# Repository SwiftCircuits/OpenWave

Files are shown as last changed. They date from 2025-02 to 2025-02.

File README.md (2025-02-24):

# OpenWave: Precision Arbitrary Waveform Generator

<div align="center">



[]()

**A dual-channel, high-precision waveform generator designed for control system analysis and system identification**

[Features](#features) • [Getting Started](#getting-started) • [Documentation](#documentation) • [Contributing](#contributing)

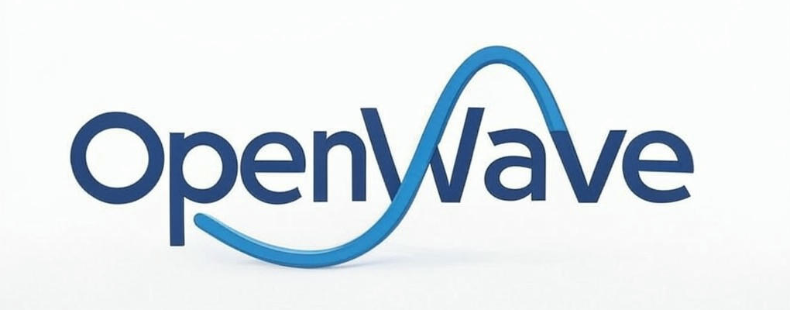
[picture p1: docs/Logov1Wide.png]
OpenWave Project Banner


</div>

## Why OpenWave?

Traditional arbitrary waveform generators often force a choice between expensive lab equipment or limited-capability hobby projects. OpenWave bridges this gap by providing professional-grade precision in an open-source design that prioritizes signal quality over raw speed. By focusing on the critical frequency range used in control systems and system identification (up to 500 kHz), we've optimized for exceptional signal quality and reliability.

### Key Features

- Dual independent channels with 16-bit resolution
- Optimized 500 kHz bandwidth with 80 dB SNR
- Sophisticated triggering system for precise control
- Multiple interface options: USB, Ethernet, and CAN
- Intuitive front panel control with LCD display
- Expansion capability through daughter board interface
- Precision temperature-monitored reference system
- Professional-grade signal filtering and conditioning

### Perfect For

- Control system development and testing
- System identification experiments
- Precision measurement applications
- Educational laboratory setups
- Research and development projects
- Industrial control system integration
- Signal processing development

## Technical Overview

OpenWave combines meticulous hardware design with flexible software to achieve exceptional signal quality:

### Signal Generation
- Dual 16-bit DACs (LTC2642-16) operating at 50 MSPS
- Third-order Sallen-Key filtering with Butterworth response
- Additional output stage conditioning
- Ultra-low noise power supply design
- Temperature-compensated reference system
- Comprehensive signal isolation and protection

### Control and Interface
- High-speed USB 2.0 interface
- 10/100 Ethernet connectivity
- Industrial-grade CAN interface
- Advanced trigger system with multiple modes:
  - Start trigger with precise timing
  - Level-sensitive pause control
  - Configurable burst mode
  - Status and peak detection outputs
- Intuitive front panel interface with LCD display

### Power System
- 12V DC input with protection
- Sophisticated multi-stage power architecture:
  - High-efficiency 5.5V pre-regulation
  - Ultra-low noise 5V analog supply
  - Clean 3.3V digital rail
  - Precision 3.3V reference
- Extensive power filtering and isolation

## Getting Started

### Current Status
This project is under active development. Current focus areas:
- Finalizing PCB layout and power distribution
- Implementing core firmware features
- Developing user interface systems
- Creating comprehensive documentation
- Establishing test procedures

### For Contributors

We welcome contributions in several areas:

**Hardware Development**
- PCB layout optimization
- Signal integrity improvements
- Power distribution refinement
- Manufacturing optimization
- Test coverage enhancement

**Firmware Development**
- STM32 core implementation
- Front panel interface development
- Communication protocol implementation
- Signal generation algorithms
- User interface refinement

**Documentation and Testing**
- System specification documentation
- Assembly and calibration procedures
- Performance verification methods
- Application examples
- User manual development

## Building OpenWave

### Hardware Requirements
- 4-layer PCB manufacturing capability
- SMD assembly equipment
- Precision test equipment:
  - Oscilloscope (>100MHz bandwidth)
  - Precision multimeter
  - Signal analyzer (recommended)
- STM32 programming capability
- Basic electronic assembly tools

### Software Requirements
- STM32CubeIDE development environment
- ARM GCC toolchain
- KiCad 7.0 or later
- Git version control
- Build system requirements (detailed in documentation)

## Documentation

> 🚧 Documentation is currently under development

Comprehensive documentation will cover:
- Complete system architecture
- Detailed theory of operation
- Assembly and testing procedures
- Calibration methodology
- Performance optimization
- Application examples
- Development guidelines

## Contributing

Your expertise can help make OpenWave better! Here's how you can contribute:

1. **Join Discussions**
   - Share your application requirements
   - Suggest performance improvements
   - Help define future features
   - Participate in design reviews

2. **Technical Contributions**
   - PCB design optimization
   - Firmware development
   - Documentation creation
   - Test procedure development
   - Performance validation

3. **Testing and Validation**
   - Prototype building and testing
   - Performance verification
   - Use case validation
   - Issue reporting and tracking

## Project Structure

```
/hardware           - KiCad design files
  /main            - Main board design
  /front_panel     - Front panel PCB
  /daughter_boards - Expansion board designs
  /manufacturing   - Production files
/firmware          - Source code
  /core            - Core STM32H7 functionality
  /front_panel     - STM32G0 interface code
  /libraries       - Shared libraries
  /tests           - Test suites
/docs              - Documentation
  /hardware        - Hardware documentation
  /firmware        - Software documentation
  /user            - User guides
  /testing         - Test procedures
```

## License

- Hardware: [CERN Open Hardware License Version 2](LICENSE-HARDWARE)
- Software: [MIT License](LICENSE-SOFTWARE)

## Acknowledgments

OpenWave builds on the work of many open-source projects and individuals. Special thanks to:
- The open hardware community for inspiration and shared knowledge
- Contributors who have helped shape the project's direction

## Contact and Support

- Create an issue for bugs or feature requests
- Join our discussions for general questions
- Email for other inquiries: constantinescu.alex02@gmail.com

---

<div align="center">

**[Back to Top](#openwave-precision-arbitrary-waveform-generator)**

</div>

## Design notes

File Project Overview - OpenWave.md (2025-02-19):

# Project Name

## Current Status
- Phase: Development
- Version: 0.1
- Last Updated: {{date}}

## Specifications
### Performance Targets
- Target 1: Value
- Target 2: Value

### Requirements
- Requirement 1
- Requirement 2

## Components Tracking

### Signal Chain
#### DAC
- Selected: Part Number
- Status: Ordered/Testing/Verified
- Performance:
    - Metric 1: Value
    - Metric 2: Value
- Issues:
    - [ ] Issue 1
    - [x] ~~Issue 2~~
        - Resolution

#### Output Stage
- Selected: Part Number
- Status: Evaluation
- Notes:
    - Observation 1
    - Observation 2

### Power System
- Architecture: Description
- Components:
    1. Component 1
        - Status
        - Performance
    2. Component 2
        - Status
        - Performance

## Development Progress

### Hardware
#### Schematic
- Status: In Progress
- Version: 0.1
- Outstanding Issues:
    - [ ] Issue 1
    - [ ] Issue 2
- Next Steps:
    - [ ] Step 1
    - [ ] Step 2

#### PCB
- Status: Planning
- Version: -
- Design Rules:
    - Rule 1
    - Rule 2
- Layout Considerations:
    - Consideration 1
    - Consideration 2

### Firmware
#### STM32CubeIDE Project
- Status: Initial Setup
- Configuration:
    - Setting 1
    - Setting 2
- Features:
    - [ ] Feature 1
    - [ ] Feature 2

#### USB Protocol
- Status: Planning
- Requirements:
    - Requirement 1
    - Requirement 2

## Testing
### Test Procedures
1. Procedure 1
    - Steps
    - Expected Results
2. Procedure 2
    - Steps
    - Expected Results

### Results
#### Test Run {{date}}
- Test 1: Pass/Fail
    - Notes
- Test 2: Pass/Fail
    - Notes

## Documentation
### User Manual
- Status: Not Started
- Sections:
    - [ ] Section 1
    - [ ] Section 2

### Technical Documentation
- Status: In Progress
- Sections:
    - [ ] Section 1
    - [ ] Section 2

## References
- Reference 1
- Reference 2

## Change Log
### Version 0.1 ({{date}})
- Initial setup
- Key decisions made

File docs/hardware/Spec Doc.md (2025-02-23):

# Arbitrary Waveform Generator

## System Overview

The arbitrary waveform generator represents a precision-focused instrument designed specifically for system identification and control system analysis applications. Operating at frequencies up to 500 kHz with 80 dB SNR, it delivers exceptional waveform generation through a dual-channel output system. The design philosophy emphasizes signal quality and measurement precision over raw speed, making it particularly suitable for control systems applications where signal integrity is paramount.

## Signal Chain Architecture

The signal generation path implements a carefully optimized serial interface approach, prioritizing signal integrity and reliability over raw throughput. The architecture centers around high-precision 16-bit DACs (LTC2642-16) with meticulous attention to power supply design and filtering to achieve superior signal quality.

Key architectural decisions include:
- Serial interface communication at 50 MHz
- Dual independent signal channels
- Hardware-level trigger processing
- Dedicated front panel processor for user interface
- Multi-stage filtering approach
- Temperature-compensated reference system

Our design philosophy acknowledges that most real-world control systems operate well below 500 kHz, allowing us to optimize for measurement accuracy and signal purity. Each component in the signal chain has been selected based on empirical evaluation and simulation results.

## Power System Architecture

The power system implements a sophisticated cascaded multi-rail design optimized for ultra-low-noise operation through a 12V input. Special attention has been paid to power supply rejection and filtering at each stage.

### Input Power
Requirements:
- 12V DC input via barrel connector (5.5mm × 2.1mm)
- Input voltage range: 11V to 13V
- Power budget: 5-7W total system draw
- Reverse polarity protection through series MOSFET
- Inrush current limiting
- Purpose: Primary system power input

### Power Rails
The system implements a carefully orchestrated cascade of power supplies:

- 5.5V Main Rail (Switching Supply):
  - Input: 12V DC
  - Output: 5.5V
  - Implementation: TPSM863252 switching regulator
  - High efficiency (>85%)
  - Switching frequency >1MHz
  - Custom RLC filter network:
    - 22µH inductor for switching noise suppression
    - Optimized capacitor values for minimal resonance
    - Damping resistors for transient response
  - Purpose: Pre-regulation for other voltage rails

- 5V Analog Rail (Low-Noise LDO):
  - Input: 5.5V from switching supply
  - Output: 5V
  - Implementation: Ultra-low noise linear regulator
  - PSRR > 80 dB at 100 kHz
  - Output noise < 10µV RMS (10Hz to 100kHz)
  - Purpose: DAC and op-amp power supply

- 3.3V Digital Rail (LDO):
  - Input: 5.5V from switching supply
  - Output: 3.3V at 500mA
  - Moderate PSRR requirements (>60 dB)
  - Fast transient response
  - Purpose: Digital logic power supply

- 3.3V Reference Voltage (Precision LDO):
  - Implementation: REF3333 precision reference
  - Initial accuracy < 0.1%
  - Temperature coefficient < 25ppm/°C
  - Ultra-low noise characteristics
  - Purpose: DAC reference voltage
  - Temperature monitored for potential compensation

### Power Distribution
The power distribution system employs:
- Separate analog and digital power planes
- Star-point grounding topology
- Independent filtering for each major subsystem
- Balanced power and return paths
- Local decoupling at each IC
- Bulk decoupling at power entry points

## Control and Communication

### Multiple Interface Options
The system implements several communication interfaces:

- USB Interface:
  - High-speed USB 2.0 implementation
  - Command protocol support
  - Streaming data capability
  - Built-in device firmware upgrade capability
  - ESD protection and filtering
  - Purpose: Primary computer interface

- Ethernet Interface:
  - Implementation: W5500 hardwired TCP/IP controller
  - 10/100 Mbps support
  - Independent 25MHz crystal
  - Magnetic isolation
  - TCP/IP protocol support
  - Purpose: Network connectivity and remote control

- CAN Interface:
  - Standard CAN 2.0B support
  - Galvanic isolation
  - Configurable bit rate up to 1Mbps
  - Termination options
  - Purpose: System synchronization and industrial control integration

### Trigger System
The trigger system provides comprehensive synchronization capabilities:

Input Triggers (3.3V logic):
- Start trigger: Initiates waveform generation
  - Rising edge sensitive
  - Configurable debounce
  - Protected input structure
- Pause trigger: Suspends output while active
  - Level-sensitive operation
  - Synchronous output suspension
  - Glitch filtering
- Burst trigger: Generates predetermined sample count
  - Software-configurable burst length
  - Precise timing control
  - Automatic termination

Output Triggers (3.3V logic):
- Started signal: Indicates active generation
  - Direct status indication
  - Low-latency response
- Peak detection: Signals waveform peaks
  - Software-configured threshold
  - Minimal delay implementation
- VRef output: Buffered reference voltage
  - Unity-gain buffered output
  - Low impedance drive
  - Filtered output stage

All triggers feature:
- EMI filtering
- ESD protection
- Schmitt trigger inputs where applicable
- Output short circuit protection

### Temperature Monitoring
The system implements dual temperature monitoring:
- Reference section sensor
  - Located near voltage reference
  - 0.5°C accuracy
  - Continuous monitoring
- Microcontroller section sensor
  - System temperature monitoring
  - Thermal protection implementation
- Look-up table based compensation
  - Temperature-dependent calibration
  - Digital compensation
- Purpose: System calibration and thermal monitoring

## Analog Signal Path

### DAC Implementation
The system utilizes dual LTC2642-16 DACs:
- 16-bit resolution
- 50 MSPS update rate
- Voltage output configuration
- Serial interface at 50 MHz
- Reference buffering
- Power supply filtering

### Output Filtering
Multi-stage filtering approach:

First Stage - Third Order Sallen-Key:
- Butterworth response characteristics
- 850 kHz cutoff frequency
- Minimal pass-band ripple
- Optimized component values
- Simulated phase response

Second Stage - Unity Gain Buffer:
- Low-noise operational amplifier
- Additional RC filtering network
- Output protection
- 50Ω drive capability

### Performance Optimization
- Careful PCB layout for analog section
- Localized power filtering
- Shield traces where necessary
- Minimize trace lengths
- Matched delay paths

## User Interface

### Front Panel Implementation
The front panel provides comprehensive user control through:

Physical Interface:
- Three precision potentiometers
  - Parameter adjustment
  - High-quality, panel-mount design
  - Metal shaft construction
- Three tactile control buttons
  - Mode selection
  - Menu navigation
  - System control
- LCD display
  - Parameter visualization
  - System status display
  - Menu system
- Five mode indication LEDs
- Status LED indicators

### Display Interface
The LCD implements:
- Current operating mode display
- Parameter value indication
- System status information
- Optional waveform preview
- Temperature and calibration status
- Menu system for configuration

## System Architecture

### Main Board
Core Components:
- STM32H743VIT6 microcontroller
  - 480 MHz operation
  - 1MB RAM
  - Extensive peripheral set
- 16 MB Flash memory
- Dual 16-bit DACs (LTC2642-16)
- Third-order Sallen-Key filters
- Unity gain output amplifiers
- Dual temperature sensors
- Level shifters for DAC communication
- Debug interfaces and indicators

### Front Panel Board
Interface Components:
- STM32G0B1 microcontroller
  - User interface handling
  - LED control
  - Parameter reading
- Interface elements
- Status indicators
- FPC connection to main board

### Expansion Capabilities
The system includes provisions for:
- Daughter board interface
  - Power distribution
  - Communication buses
  - Control signals
- Additional filtering options
- Enhanced trigger capabilities
- Wireless connectivity options

## PCB Implementation

### Board Architecture
- 4-layer implementation
- Layer stack-up:
  - Top: Signal
  - Layer 2: Ground plane
  - Layer 3: Power planes
  - Bottom: Signal and power
- Controlled impedance throughout
- Single ground plane philosophy
- Careful return path consideration

### Critical Areas
- Analog section isolation
- Power supply placement
- Ground plane integrity
- High-speed signal routing
- Thermal considerations

### Manufacturing Considerations
- Standard FR4 material
- 1oz copper weight
- Controlled impedance requirements
- Through-hole and SMD mixed technology
- Assembly considerations
- Test point access

## Performance Specifications

### Signal Generation
- Maximum frequency: 500 kHz
- Resolution: 16-bit
- SNR: > 80 dB
- THD: < -75 dB
- Output filtering: Third-order Butterworth
- Channel-to-channel skew: < 10ns

### System Operation
- Trigger latency: < 100ns
- Temperature stability: < 50ppm/°C
- Start-up time: < 100ms
- USB/Ethernet latency: < 1ms typical

## Future Considerations

The design includes provisions for:
- Additional interface options
- Enhanced trigger capabilities
- Wireless connectivity through daughter boards
- Advanced filtering implementations
- Remote control capabilities
- Battery operation options

Note: All specifications subject to verification during detailed design phase.

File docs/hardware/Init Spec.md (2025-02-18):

# Arbitrary Waveform Generator: System Architecture and Requirements

## System Overview

The arbitrary waveform generator is designed as a USB-powered, battery-backed device for system identification and control system analysis. Operating at frequencies up to 8 MHz with 60 dB SNR, it provides precise waveform generation through a dual-channel output system.

## Signal Chain Architecture

The signal generation path is designed around a serial interface approach, prioritizing reliability and simplicity over raw speed. This architectural choice shapes our entire signal chain, from memory management to analog output stage.

Our design philosophy emphasizes practical performance targets that align with real-world control system needs. For system identification work, timing consistency and signal quality are more critical than extremely high frequencies. Each component in our signal chain is selected with this philosophy in mind:

### Digital Signal Generation
Primary MCU requirements:
- DMA capabilities for continuous data streaming
- Hardware floating-point for mathematical operations
- Multiple high-resolution timer units
- Sufficient GPIO for parallel DAC interface
- USB peripheral with high-speed capability
- CAN peripheral for auxiliary communication

### Memory System

### Memory Strategy and Buffer Management

Our memory architecture is built around the capabilities of modern microcontrollers, taking advantage of their substantial internal RAM and efficient DMA controllers. This approach eliminates the complexity and potential signal integrity issues of external RAM while providing more than adequate performance for our needs.

Memory Requirements Analysis:
At our target 100 MSPS with 12-bit samples, our theoretical bandwidth is 1.2 Gbps per channel. However, our SPI interface serializes this data at up to 100 MHz, making the actual memory throughput requirements much more manageable. For a typical 1ms control system time step, we need only 150 KB per channel including double buffering, well within the capabilities of modern MCU internal RAM.

RAM Organization:
- Primary waveform buffer in internal MCU RAM, eliminating external memory complexity
- Double-buffering scheme for seamless output, with each buffer sized for complete control system time steps
- Buffer sizing follows: (sample_rate × bits_per_sample × channels × buffer_time)
- Typical buffer depth: 4-16K samples per channel, optimized for common control system update rates

DMA Configuration:
- Circular buffer mode for continuous output
- Interrupt on half-buffer completion
- Buffer swap without output glitches
- Error detection and recovery mechanisms

Purpose: 
- Ensuring continuous waveform generation
- Supporting real-time parameter updates
- Maintaining timing accuracy
- Enabling smooth transitions between waveforms
- Concurrent access capability for DMA and CPU
- Purpose: Active waveform buffers and computation workspace

Flash Storage Requirements:
- QSPI interface for high-speed access
- Minimum 32 Mbit capacity
- Purpose: 
  - Storage for custom waveform patterns
  - Configuration settings
  - Calibration data
  - Lookup tables for standard waveforms

### Digital-to-Analog Conversion

DAC Requirements:
- 50-100 MSPS update rate with SPI/I²S interface
- 10-bit resolution
- Parallel interface to minimize latency
- Current-output architecture
- SNR > 60 dB
- THD < -60 dB
- Settling time < 3ns
- Purpose: Converting digital patterns to analog signals

### Analog Output Stage

Amplification Requirements:
- Bandwidth > 100 MHz
- Slew rate > 1000 V/µs
- Output current > 50mA for 50Ω loads
- Input bias current < 1µA
- Low input-referred noise (< 5 nV/√Hz)
- Power supply rejection > 60 dB
- Purpose: Signal conditioning and impedance matching

### Clocking System

Initial Implementation:
- External crystal oscillator as reference
- Internal PLL for frequency generation
- Clock distribution with controlled impedance
- Purpose: System timing and DAC clock generation

Future Upgrade Path:
- Space for dedicated clock generator
- Power supply provisions
- Clock distribution routing channels
- Test points for performance verification

## Power System Architecture

The power system implements a multi-rail design with separate charging and operational paths:

### Input and Charging
Requirements:
- USB power negotiation (5V, up to 3A)
- Separate charging and operational paths
- Battery protection features
- Charge status monitoring
- Purpose: Power input and battery management

### Power Rails
Multiple independent supplies:
- 3.3V Digital Rail:
  - Low noise for digital circuits
  - High current capability
  - Fast transient response
  - Purpose: Digital logic power

- 3.3V Analog Rail:
  - Ultra-low noise (< 10µV RMS)
  - High PSRR (> 80 dB)
  - Purpose: Sensitive analog circuits

- 5V Analog Rail:
  - Low noise characteristics
  - High current capability
  - Purpose: Op-amp power supply

- Reference Voltage:
  - Ultra-stable output
  - Temperature compensated
  - Purpose: DAC reference

### Battery Management
Requirements:
- Lithium battery support
- Smart charging control
- Voltage and current monitoring
- Temperature monitoring
- Purpose: Portable operation support

## Control and Communication

### USB Interface
Requirements:
- High-speed USB 2.0 capability
- Robust USB power delivery
- Command protocol support
- Streaming data capability
- Purpose: Primary computer interface

### CAN Interface
Requirements:
- Standard CAN 2.0B support
- Isolated interface
- Configurable bit rate
- Purpose: System synchronization and auxiliary control

### Temperature Monitoring
System includes:
- Two temperature sensors
- Compensation algorithms
- Purpose: System calibration and thermal monitoring

## PCB Design Requirements

### Signal Integrity
- Controlled impedance for critical traces
- Proper stackup for high-speed signals
- Ground plane strategy
- Power plane partitioning
- Purpose: Maintaining signal quality

### Layout Considerations
- Separate analog and digital sections
- Critical component placement
- Thermal management
- EMI mitigation
- Future upgrade provisions
- Purpose: System performance optimization

## Calibration System

### Temperature Compensation
- Regular sensor sampling
- Gradient monitoring
- Compensation tables
- Purpose: Maintaining accuracy across temperature

### Signal Calibration
- Gain calibration
- Offset adjustment
- Frequency response characterization
- Purpose: Output accuracy verification

## Outputs and Interfaces

### Signal Outputs
- Two independent channels
- 50Ω output impedance
- Voltage range: 0 to 3.3V
- BNC or SMA connectors
- Purpose: Waveform output

### Trigger System
Implementation Strategy:
- Utilize MCU internal comparators for trigger detection
- Internal reference voltage for threshold setting
- Software-configurable hysteresis
- Timer-based output generation

Input Characteristics:
- Voltage range: 0-3.3V
- Software-adjustable threshold
- Configurable hysteresis through MCU comparator
- Input protection with current limiting and TVS
- Minimum pulse width: 100ns

Output Characteristics:
- 3.3V CMOS level output
- Timer-controlled for precise timing
- Programmable delay (100ns resolution)
- Short circuit and ESD protected
- Drive capability: up to 8mA

This approach simplifies hardware while maintaining functionality through careful use of MCU peripherals.
- Purpose: System synchronization

## Performance Targets

### Signal Generation
- Maximum frequency: 8 MHz
- SNR: > 60 dB
- THD: < -60 dB
- Channel-to-channel skew: < 10ns

### System Operation
- Initial lock time: < 100ms
- Trigger latency: < 100ns
- Temperature stability: < 50ppm/°C
- Battery operation: > 2 hours continuous

## Future Expansion Considerations

The design includes provisions for:
- Dedicated clock generator upgrade
- Additional memory expansion
- Enhanced trigger capabilities
- Ethernet interface addition
- Purpose: Future feature enhancement

Note: This specification focuses on system properties and requirements rather than specific component selections. Implementation details will be determined during the detailed design phase.

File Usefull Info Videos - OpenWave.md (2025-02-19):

# Mixed-Signal Design Guidelines for AWG Project
*Extracted from [Phil's Lab video](https://www.youtube.com/watch?v=v6fTa6LRJLI&ab_channel=Phil%E2%80%99sLab), focusing on principles relevant to our arbitrary waveform generator design*

## 1. Ground Plane Management (0:00-4:39)
For our AWG design, the key takeaways are:
- Use a unified ground plane unless there's a compelling reason not to
- In our 4-layer design, we should maintain solid ground planes on inner layers
- Keep signal traces away from voids in the ground plane
- Maintain minimum spacing between signal and ground layers
  - Recommended: 0.11mm between layers for optimal coupling
- This directly applies to our STM32H743 + LTC2642 DAC design

## 2. Digital-Analog Separation (4:39-9:24)
Critical for our AWG implementation:
- Place digital section (STM32H743, flash memory) distinctly separate from analog section (DAC, op-amps)
- Use the DAC's pinout to define the boundary:
  - Digital interface pins should face the digital section
  - Analog pins should face the analog section
- Consider 3D separation if board space is tight
- Implement via fencing between domains:
  - Space vias at maximum 1/10th of the wavelength of highest frequency of interest
  - For our 2-5MHz design, this gives us a good margin

## 3. Domain Crossing Strategy (9:24-11:55)
Applicable to our control signals:
- Use Pi filters when crossing from digital to analog domains
- Filter composition:
  - Capacitor on digital side
  - Series element (resistor or ferrite bead)
  - Capacitor on analog side
- Particularly important for our MCU control signals to the analog section
- Consider edge rate reduction for digital signals entering analog domain

## 4. Power Supply Separation (11:55-15:09)
Directly relevant to our power architecture:
- Maintain separate supplies for digital and analog sections
- Our implementation matches recommendations:
  - Digital: 3.3V with higher current capacity for STM32
  - Analog: Clean 3.3V reference for DAC
  - 5V rail for op-amps
- Use Pi filters for power supply noise reduction
- Place initial filter near input connector
- Consider additional filtering for analog supplies

## 5. Component Selection Guidelines (15:09-17:47)
Critical considerations for our design:
- Power regulators: Check noise specifications and PSRR
- For our DAC and op-amps:
  - Consider pin arrangement for optimal layout
  - Look for clear separation between digital and analog pins
  - Check noise specifications and settling time
- Consider package types that facilitate clear domain separation

## Implementation Notes for Our AWG
- Our proposed LTC2642 DAC aligns well with these guidelines, having clear digital/analog pin separation
- The LMH6658 op-amp choice supports our bandwidth requirements while maintaining good noise characteristics
- The power system design with TPSM863252 and separate LDOs follows these recommendations
- Consider adding more via fencing between domains in the next revision

# Thermal Design Guidelines for AWG Project
*Extracted from [Phil's Lab video](https://www.youtube.com/watch?v=8v-wC5cM_Yk&ab_channel=Phil%E2%80%99sLab), focusing on principles relevant to our arbitrary waveform generator design*

## Power Plane Dimensioning (1:17-4:30)
Our AWG design requires careful consideration of power distribution, particularly for the analog and digital domains. The key principles to apply are:

The IPC-2221 specification provides the foundation for calculating appropriate trace widths. For our design, we should consider:
- Different requirements for internal vs. external layers (internal layers need ~2.5x wider traces)
- Temperature rise calculations based on our expected operating environment
- Non-linear relationship between current capacity and trace width

For our specific power rails:
- 12V input: Requires wide traces due to higher current
- 5V rail (TPSM863252): Must handle 1.5A minimum
- 3.3V digital (for STM32): Needs ~500mA capacity
- 3.3V analog: Lower current (~200mA) but requires special attention to noise

## Linear Regulator Considerations (7:03-11:55)
This section is particularly relevant for our design's analog power supplies. Key points:

Power Dissipation Calculation:
```
P_dissipated = (V_in - V_out) × I_out
```

For our design:
- TPS70933DBVR (3.3V analog): Must consider noise and thermal characteristics
- AP7363-33D (3.3V digital): Higher current requires better thermal management
- REF3333 (precision reference): Requires stable temperature for accuracy

## Package Selection Guidelines (9:42-13:15)
Critical considerations for our power components:

Thermal Resistance:
- Junction-to-ambient thermal resistance (θJA) is crucial
- Larger packages generally offer better thermal performance
- Thermal pad presence significantly impacts heat dissipation

For our specific components:
- TPSM863252: Must handle the highest power dissipation
- Linear regulators: Need careful thermal design due to voltage drop
- Reference voltage IC: Requires temperature stability for accuracy

## Thermal Via Implementation (13:16-18:00)
Essential guidelines for our power components:

Via Design:
- Optimal via hole diameter: 0.25mm - 0.3mm
- Multiple parallel vias reduce thermal resistance
- Place vias directly under thermal pads
- Consider solder wicking during assembly

For our layout:
- Place thermal vias around regulator thermal pads
- Connect to internal ground planes for heat spreading
- Consider additional copper pours for better heat dissipation

## Application to Our AWG Design
Specific recommendations for our implementation:

1. Power System Layout:
   - Separate analog and digital power planes
   - Use thermal relief for through-hole components
   - Implement copper balancing for assembly reliability

2. Component Placement:
   - Keep heat-generating components (TPSM863252, linear regulators) separated
   - Consider airflow patterns in enclosure
   - Maintain thermal isolation between analog and digital sections

3. Thermal Management Strategy:
   - Use multiple ground planes for heat spreading
   - Implement proper thermal via arrays under power components
   - Consider ambient temperature range (0°C to 50°C per spec)

4. Critical Areas Requiring Attention:
   - Main switching regulator (TPSM863252)
   - Analog supply linear regulator
   - Precision voltage reference
   - Output amplifier stage

By following these guidelines, we can ensure reliable operation across our specified temperature range while maintaining the signal integrity required for precise waveform generation.

# RF Design Guidelines for AWG Project
*Extracted from [Phil's Lab video](https://www.youtube.com/watch?v=_Hfzq1QES-Q&t=2s&ab_channel=Phil%E2%80%99sLab), with focus on principles relevant to our arbitrary waveform generator design operating up to 5MHz*

## Critical Length Calculations (0:00-4:42)
While our AWG operates at lower frequencies than typical RF designs, understanding critical length is still important for signal integrity. The critical length determines when we need to consider transmission line effects:

For microstrip traces (outer layer):
```
Critical Length = (c / f) × (1 / √εeff) / 12

Where:
c = speed of light (3×10⁸ m/s)
f = frequency of interest
εeff = effective dielectric constant
```

For our maximum frequency of 5MHz:
- Critical length ≈ 2.5 meters
- While this suggests we don't need strict RF practices, following good RF design principles will improve signal quality

## PCB Stack-up Considerations (4:42-8:51)
For our 4-layer design:

Inner layers:
- Layer 2: Solid ground plane under analog sections
- Layer 3: Power distribution and additional ground

Outer layers:
- Top layer: Signal routing with controlled impedance where needed
- Bottom layer: Additional routing and ground planes

This arrangement provides excellent shielding and signal integrity for our analog sections.

## Controlled Impedance Traces (8:51-12:33)
For our analog output path:

Calculating trace width for 50Ω impedance:
- Consider PCB manufacturer's stack-up specifications
- For typical 4-layer board with FR4 (εr = 4.6):
  - Height to reference plane: 0.2mm
  - 1oz copper thickness: 35µm
  - Resulting trace width: approximately 0.3mm

## Managing Impedance Discontinuities (12:33-14:33)
Particularly important for our DAC output and op-amp sections:

- When transitioning from component pads to traces:
  - Use gradual transitions rather than abrupt changes
  - For our DAC outputs, implement smooth tapering from pads
  - Consider via transitions carefully near sensitive analog paths

## Clearance Guidelines (14:33-15:18)
Critical for maintaining signal integrity:

Component Placement Strategy:
- Keep DAC and analog output section well separated from digital circuits
- Maintain distance between high-speed digital signals and analog paths
- Consider magnetic field effects from power supply components
- Place sensitive analog components away from switching regulators

## Application to Our AWG Design
Specific recommendations for implementation:

Signal Path Design:
1. DAC Output Stage:
   - Implement controlled impedance traces for critical analog paths
   - Use gradual transitions from DAC output pads
   - Maintain consistent ground reference under signal paths

2. Analog Power Distribution:
   - Keep analog power planes well-isolated from digital sections
   - Use separate ground planes for analog and digital domains
   - Implement star grounding topology for analog sections

3. Component Placement:
   - Group analog components together
   - Maintain maximum practical separation between analog and digital sections
   - Consider airflow and thermal effects on precision components

4. Critical Areas Requiring Special Attention:
   - DAC output traces
   - Op-amp feedback networks
   - Reference voltage distribution
   - Analog power supply traces

## Implementation Notes
While our maximum frequency of 5MHz doesn't require strict RF practices, following these guidelines will improve performance:

1. Signal Path:
   - Use controlled impedance where practical
   - Maintain ground plane integrity
   - Keep analog traces short and direct

2. Shielding:
   - Use ground planes effectively
   - Consider local shielding for sensitive sections
   - Implement proper via fencing around analog sections

3. Grounding:
   - Use solid ground planes
   - Implement proper ground separation
   - Consider return current paths

By following these guidelines, we can ensure optimal signal integrity and minimize unwanted interference in our AWG design, even though we're operating at relatively lower frequencies than typical RF applications.

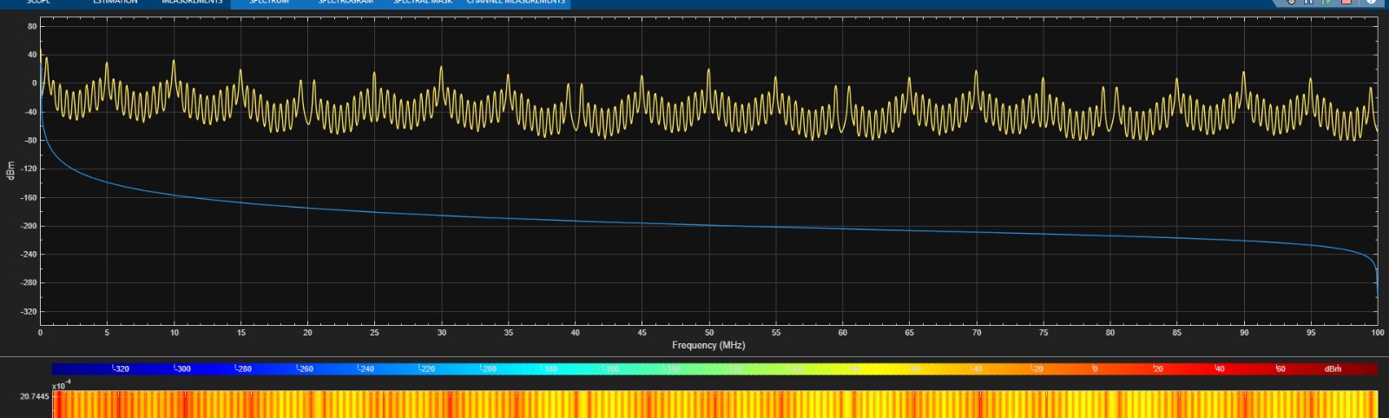
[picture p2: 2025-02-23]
docs/hardware/PowerFilterResponse.jpg

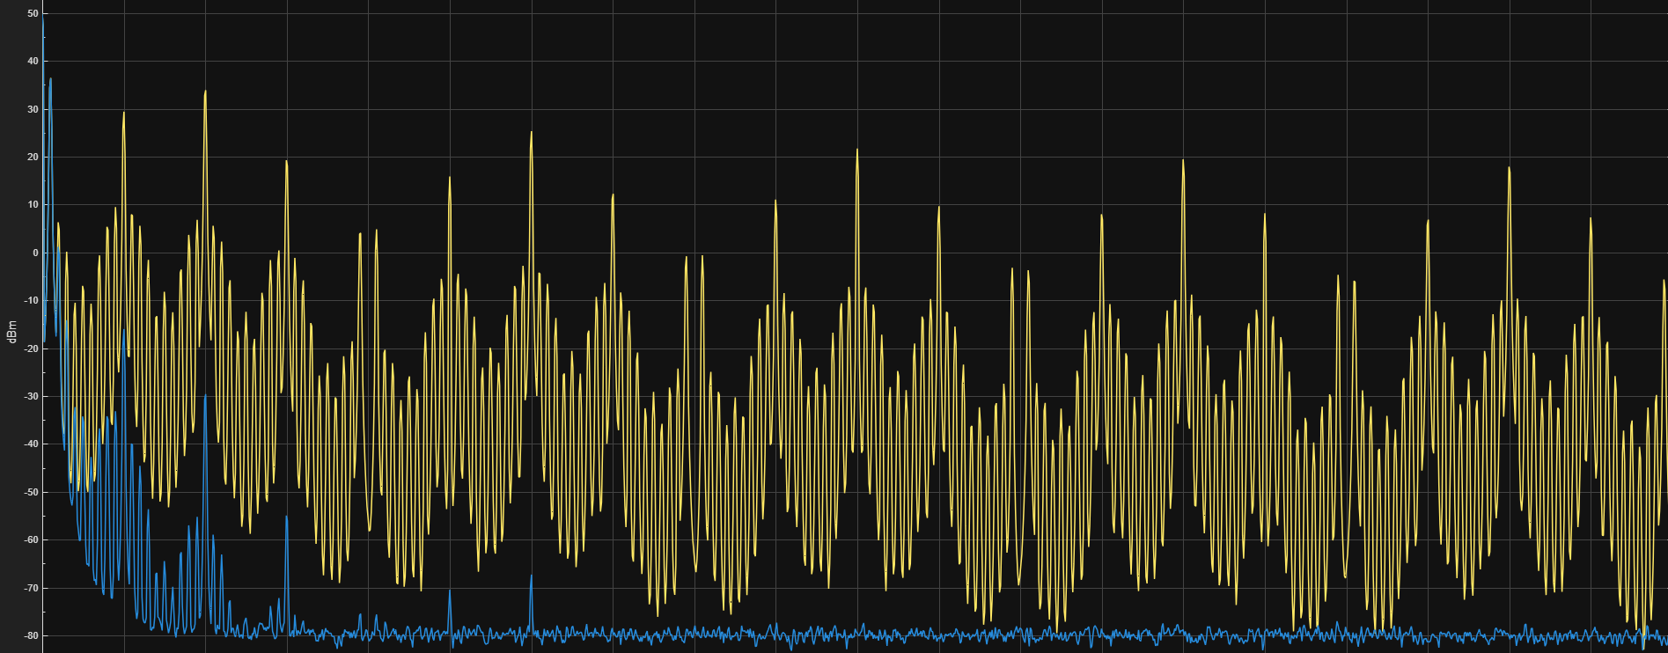
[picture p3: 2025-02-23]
docs/hardware/OutputFilterResponse.png

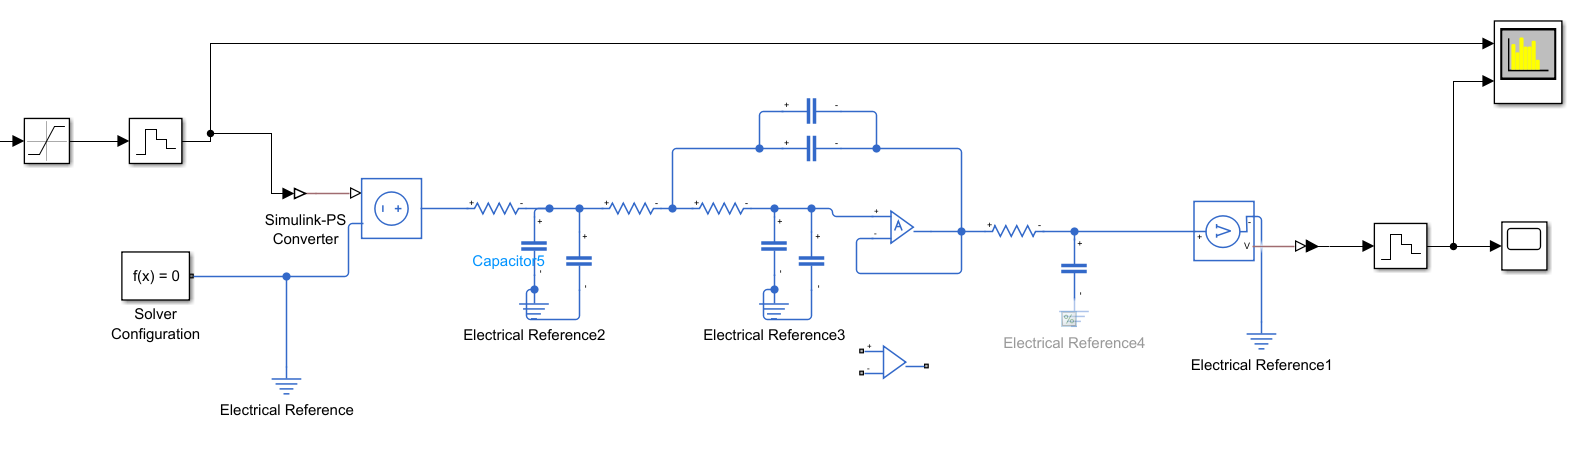
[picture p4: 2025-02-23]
docs/hardware/OutputFilterDesign.png

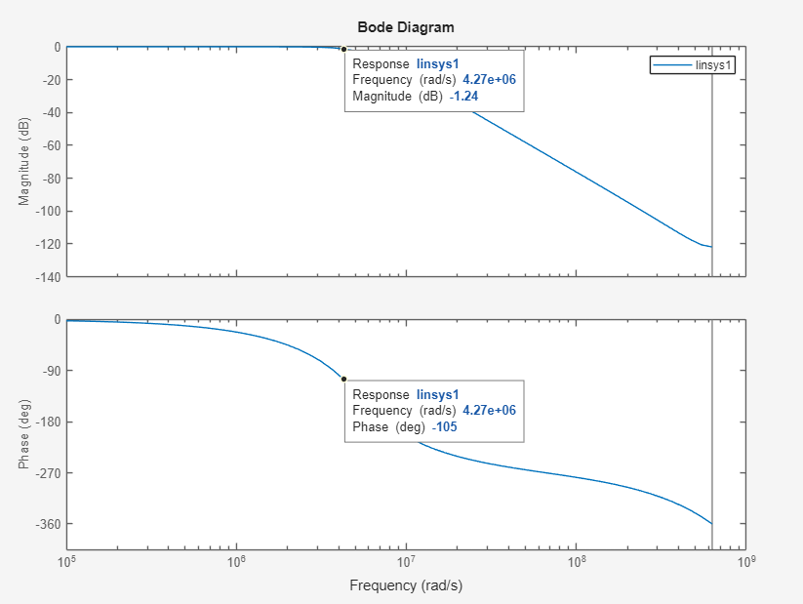
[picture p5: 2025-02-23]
docs/hardware/OutputFilterBode.png

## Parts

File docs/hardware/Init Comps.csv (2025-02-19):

Component Name | Component Type | Use | Option 1 | Link 1 | JLC # | Option 2 | Link 2 | Spec
DAC | Digital-to-Analog Converter | Signal Generation | LTC2642IMS-12#PBF | https://ro.mouser.com/ProductDetail/Analog-Devices/LTC2642IMS-12PBF?qs=hVkxg5c3xu%2FRHnABAf4DOg%3D%3D | C580595 | AD5512AACPZ | https://ro.mouser.com/ProductDetail/Analog-Devices/AD5512AACPZ-REEL7?qs=NmRFExCfTkH4RrvEIUo0Ug%3D%3D | 50-100 MSPS via SPI; 12-bit resolution; SNR > 60 dB; THD < -60 dB; Settling time < 5ns
Output Amplifier | Operational Amplifier | Signal Conditioning | LMH6658MAX/NOPB | https://ro.mouser.com/ProductDetail/Texas-Instruments/LMH6658MAX-NOPB?qs=7lkVKPoqpbYvQxLHeSqxGQ%3D%3D | N/A | LMH6624MF/NOPB | https://jlcpcb.com/partdetail/TexasInstruments-LMH6639MFNOPB/C131982 | Bandwidth > 100 MHz; Slew rate > 500 V/Âµs; Output current > 50mA for 50Î© loads; Low noise < 5 nV/âˆšHz
MCU | Microcontroller | System Control | STM32H743VIT6 | https://ro.mouser.com/ProductDetail/STMicroelectronics/STM32H743VIT6?qs=FNcb6ahWXRw0Me5k2ZHgWw%3D%3D | C114409 | N/A | N/A | ARM Cortex-M4/M7; â‰¥100MHz; 256KB Flash; 128KB RAM; USB; SPI; CAN; ADC 12-bit
Battery Management IC | Power Supply | Clean Analog Power | TPS70933DBVR | https://ro.mouser.com/ProductDetail/Texas-Instruments/TPS70933DBVR?qs=Z9twEOuL%252B%2FJOaGO60BtvLA%3D%3D | C89347 | TBD-REG2 | # | 3.3V output; Ultra-low noise (<10ÂµV RMS); High PSRR (>80 dB)
 | Power Supply | Digital Logic Power | AP7363-33D-13 | https://ro.mouser.com/ProductDetail/Diodes-Incorporated/AP7363-33D-13?qs=wo71MgyKIyHiOg1BWxA5bA%3D%3D | C108723 | TBD-REG4 | # | 3.3V output; High current capability; Fast transient response
Voltage Regulator (3v3 Analog) | Power Supply | Clean Analog Power | TPSM863252 | https://ro.mouser.com/ProductDetail/Texas-Instruments/TPSM863252RDXR?qs=17ckDYBRdem3VGqByrpWcQ%3D%3D | C19190416 | TBD-REG6 | # | 5V output; Fast transient response
Voltage Regulator (3v3 Digital) | Power Supply | Stable Ref Voltage | REF3333AIDBZR | https://ro.mouser.com/ProductDetail/Texas-Instruments/REF3333AIDBZR?qs=7KoJEllG3D1OY7cEjajdfg%3D%3D | C130016 | TBD-REF2 | # | 3.3V output; Very high stability (Zener?)
Voltage Regulator (5V Analog) | USB Controller | PC Communication | TBD-USB1 | # |  | TBD-USB2 | # | USB 2.0 Full Speed; 5V tolerance; ESD protection
Voltage Reference (3v3) | Communication Interface | CAN Bus Interface | TBD-CAN1 | # |  | TBD-CAN2 | # | CAN 2.0B compatible; 3.3V interface; ISO1050 compliant
USB Interface | Clock Source | System Timing | TBD-XTAL1 | # |  | TBD-XTAL2 | # | High stability; Low phase noise; Temperature compensated
CAN Transceiver | User Input | Parameter Control | TBD-POT1 | # |  | TBD-POT2 | # | 10-100kÎ©; 1% linearity; Metal shaft; >10k cycle life
Crystal Oscillator | Status Indicator | User Feedback | TBD-LED1 | # |  | TBD-LED2 | # | 3mm or 5mm; 5mA operation; Various colors; 120Â° viewing angle
Potentiometer | User Input | Control Selection | TBD-SW1 | # |  | TBD-SW2 | # | Tactile feedback; 100k cycle life; 150-250gf operating force
LED | Protection | I/O Protection | TBD-TVS1 | # |  | TBD-TVS2 | # | Low capacitance; Fast response; Appropriate voltage rating
Tactile Switch | Connector | Power & Data Input | TBD-USBC1 | # |  | TBD-USBC2 | # | USB 2.0 compatible; Through-hole mounting; 5A current rating; Shielded
TVS Diode | Connector | Signal Output | TBD-BNC1 | # |  | TBD-BNC2 | # | 50Î© impedance; Panel mount; Gold plated; DC-1GHz bandwidth
USB-C Connector | Connector | Battery Connection | TBD-BATCON1 | # |  | TBD-BATCON2 | # | JST-PH or similar; 2A rating; Polarized; Locking
BNC Connector | Connector | Programming/Debug | TBD-DBG1 | # |  | TBD-DBG2 | # | SWD compatible; 2x5 1.27mm pitch; Keyed
Battery Connector | Connector | CAN Bus | TBD-CANCON1 | # |  | TBD-CANCON2 | # | 4-pin locking; Polarized; 2A rating
Debug Connector | Storage | Waveform Storage | TBD-FLASH1 | # |  | TBD-FLASH2 | # | 32Mbit minimum; SPI interface; >10MHz clock
CAN Connector | Protection | Battery Safety | TBD-BPROT1 | # |  | TBD-BPROT2 | # | Overcurrent; Overvoltage; Temperature protection
Flash Memory | EMI Suppression | Power Filtering | TBD-FB1 | # |  | TBD-FB2 | # | 600Î© @ 100MHz; 1.5A rating
Battery Protection | Passive | Power Decoupling | TBD-CAP1 | # |  | TBD-CAP2 | # | 0.1ÂµF & 10ÂµF X5R/X7R; Low ESR
Ferrite Bead | Passive | Power Filtering | TBD-IND1 | # |  | TBD-IND2 | # | 10ÂµH; Low DCR; >1A rating
Bypass Capacitors | Passive | Current Monitoring | TBD-RSENSE1 | # |  | TBD-RSENSE2 | # | 0.05Î©; 1%; 0.5W
Power Inductors | Sensor | Thermal Monitoring | TBD-TEMP1 | # |  | TBD-TEMP2 | # | Â±1Â°C accuracy; I2C interface
Current Sense Resistor | Passive | LED Control | TBD-RLED1 | # |  | TBD-RLED2 | # | Appropriate value for 5mA; 1%
Temperature Sensor | Protection | Interface Protection | TBD-ESD1 | # |  | TBD-ESD2 | # | Low capacitance; USB compatible
LED Current Limiting Resistors | Power Source | Portable Power | TBD-BAT1 | # |  | TBD-BAT2 | # | Li-Ion 3.7V; >2000mAh; With protection
ESD Protection Array | Mechanical | Housing | TBD-ENC1 | # |  | TBD-ENC2 | # | Suitable size; Ventilation; Panel mount support
Battery | Mechanical | Potentiometer Control | TBD-KNOB1 | # |  | TBD-KNOB2 | # | Metal shaft compatible; Indicator line
Enclosure | Thermal | Amplifier Cooling | TBD-HS1 | # |  | TBD-HS2 | # | Appropriate size; Low thermal resistance
Knobs
Heat Sink

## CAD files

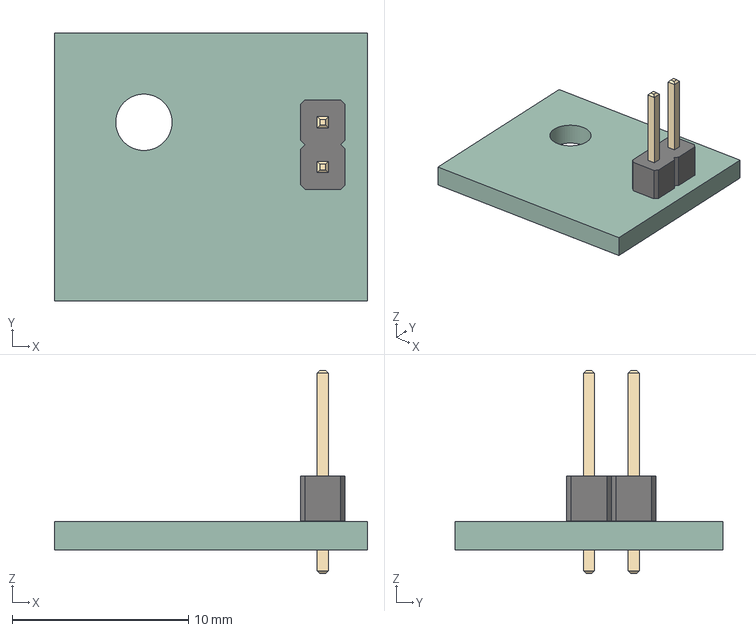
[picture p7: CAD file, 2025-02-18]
hardware/main/OpenWave_Init/OpenWave_Init.step
17.8 x 15.2 x 11.5 mm
PinHeader_1x02_P254mm_Vertical
OpenWave_Init_PCB

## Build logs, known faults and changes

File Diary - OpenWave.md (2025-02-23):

# 2025
## February
### 18
1. Started with ambitious specs: 30MHz, 8-10 bit, dual-channel AWG
2. Initial architecture: Parallel DAC (MCP4922) and external SRAM (23LC1024)
3. After analysis, found serious implementation challenges:
    - Parallel interface requires complex timing and many GPIO lines
    - Memory bandwidth requirements extremely high (3 Gbps)
    - Output stage needs expensive high-speed op-amps
4. Strategic compromises for first prototype:
    - Reduced target to 5MHz while maintaining SNR goals (60 dB)
    - Switched to SPI DAC (LTC2642 at 50 MSPS)
    - Using MCU internal RAM instead of external SRAM
    - Selected LMH6658 op-amp 
    - Added physical controls for standalone operation
5. Design simplifications without compromising core functionality:
    - MCU internal comparators for trigger system
    - Double buffering scheme in MCU RAM
    - Focused on 50Ω load capability
    - Added CAN for future expansion
    - Removed battery backup functionality to reduce complexity
    - Switched from USB power to 12V input for better power budget
6. Power Architecture Refinement:
    - Implemented three-stage power system:
        - 12V to 5V switching (TPSM863252)
        - Separate 3.3V analog/digital LDOs
        - Precision 3.3V reference (REF3333)
    - Accepted slightly higher noise on analog supply (TPS70933DBVR) after analyzing complete signal chain
7. Selected Core Components:
    - STM32H743VIT6 MCU (480MHz, 1MB RAM)
    - LTC2642 12-bit DAC
    - LMH6658 Op-amp
    - REF3333 Voltage Reference

Current Implementation Path:

- Revised specs to 5MHz with 60 dB SNR/THD
- First prototype focusing on reliable operation
- Added practical features (standalone operation, CAN)
- Designed for realistic hobbyist manufacturing
- Structured power system for clean signal generation
- Clear subsystem testing strategy:
    1. Power supply validation
    2. Digital section
    3. DAC interface
    4. Analog output stage
- Left upgrade paths for future performance improvements

Engineering Notes:

- Power budget calculations show ~5-7W total system draw
- Analyzed noise chain through power supplies and op-amp
- Memory requirements well within MCU capabilities
- Digital current draw estimated at ~250mA worst case
- Temperature considerations for voltage reference critical
### 19

#### Key Decisions
- Stepped requirements down to 2MHz
- Decided to use PCBs for Front and Back Panels

#### Daily TODO

- [ ]  Complete STM32CubeIDE basic setup
- [x]  Start power distribution schematic
- [x]  Research mixed-signal board layout guidelines

#### End of Day Notes

- Schematic done around STM32 and Power System
- Changed power arhitecture, now stepping 12V down to 5.5V which is split across the 2 LDOs and the VRef generator, one of the LDOs now is a fixed 5V one with filtering (for better DAC/OpAmp Performance)

#### Tasks

1. STM32CubeIDE Project Setup
    
    ##### Progress
    
    - HSE configured at 25 MHz
    - Clock configuration auto-solved
    - SWD debugging enabled
    - Enabled peripherals:
        - FDCAN
        - SPI
        - QSPI: Bank 1 with Quad SPI Lines
        - USB_OTG_FS - Device - CDC
    
    ##### TODO
    
    - [ ]  Optimize clock tree configuration
    - [ ]  Complete DMA setup
    - [x]  Review USB device class options
    
    ##### Issues
    
    - [x]  ~~RCC CRC SYNC confusion~~
        - Solution: This is CRS_SYNC (Clock Recovery System)
        - Used for USB SOF synchronization
    - [x]  ~~PWR Monitoring State~~
        - Solution: Always active, UI toggle for external only
    - [x]  ~~USB VBUS handling~~
        - Solution: PA9 with voltage divider
    
    ##### Notes
    
    - Clock auto-configuration creates too many divisions
    - May need to revisit USB configuration for custom device class
    - DMA priority scheme needs careful consideration
2. Schematic Design
    
    ##### Progress
    
    - Started STM32H743VIT6 section
    - Added backup battery circuit
    
    ##### TODO
    
    - [x]  Review crystal layout requirements
    
    ##### Notes
    
    - VBat connected through solder jumper
    - Consider adding test points for power rails

#### References

- STM32H743 Reference Manual
- AN4950: Crystal oscillator configuration
- Mixed-signal PCB design guidelines
### 20

#### Key Decisions
- Reduced Battery to 20 mm size - 30 is too much!
- Decided that front panel will have dedicated extremely low cost STM32 to handle I/O
- Related to above, decided on a simple LCD Screen.

#### Today's Goals
- [ ] Finish up most of the core schematic
- [ ] Review Core Schematic

#### Tasks

1. Schematic
    ##### TODO
    - [x] Fix step-down divider to get 5.5V instead of 5V
    - [ ] Add debug options ( Test Points, LEDs, UART )
    - [x] Add CAN
    - [x] Connect everything to the STM after initial layout considerations
    
    ##### NOTES
    - After hours of intense thought, decided to keep current DAC with only 2 MHz usable and 12 bit due to simplicity in this initial version

#### End of Day Notes
- Finished V0.1 of Schematic with connections
- Decided I must learn to simulate filter response and design.

#### Gallery
![[OpenWave_Init.pdf]]
- Caption: Init version of full Schematic

### 22

Extra note: Spend 21 and most of 22 learning Simscape and Simulink to simulate some filters
#### Key Decisions
- Decided to implement 3rd order Sallen-Key with Butterworth response on the output from the DAC.

#### Today's Goals
- [ ] Finish filter design and implementation

#### Tasks

1. Filter
    ##### TODO
    - [ ] Consult with mentor on ideal power filter cut-off freq
    
    ##### NOTES
    - Basically filtering anything above 850 kHz. I love it how I started with 20 MHz in plan haha

#### End of Day Notes
- Made a filter
  - Essential for proper output

#### Gallery
![[OutputFilterResponse.png]]
- Caption: Output Filter Response
![[OutputFilterDesign.png]]
- Caption: Output Filter Design
![[PowerFilterResponse.jpg]]
- Caption: Power Filter Response

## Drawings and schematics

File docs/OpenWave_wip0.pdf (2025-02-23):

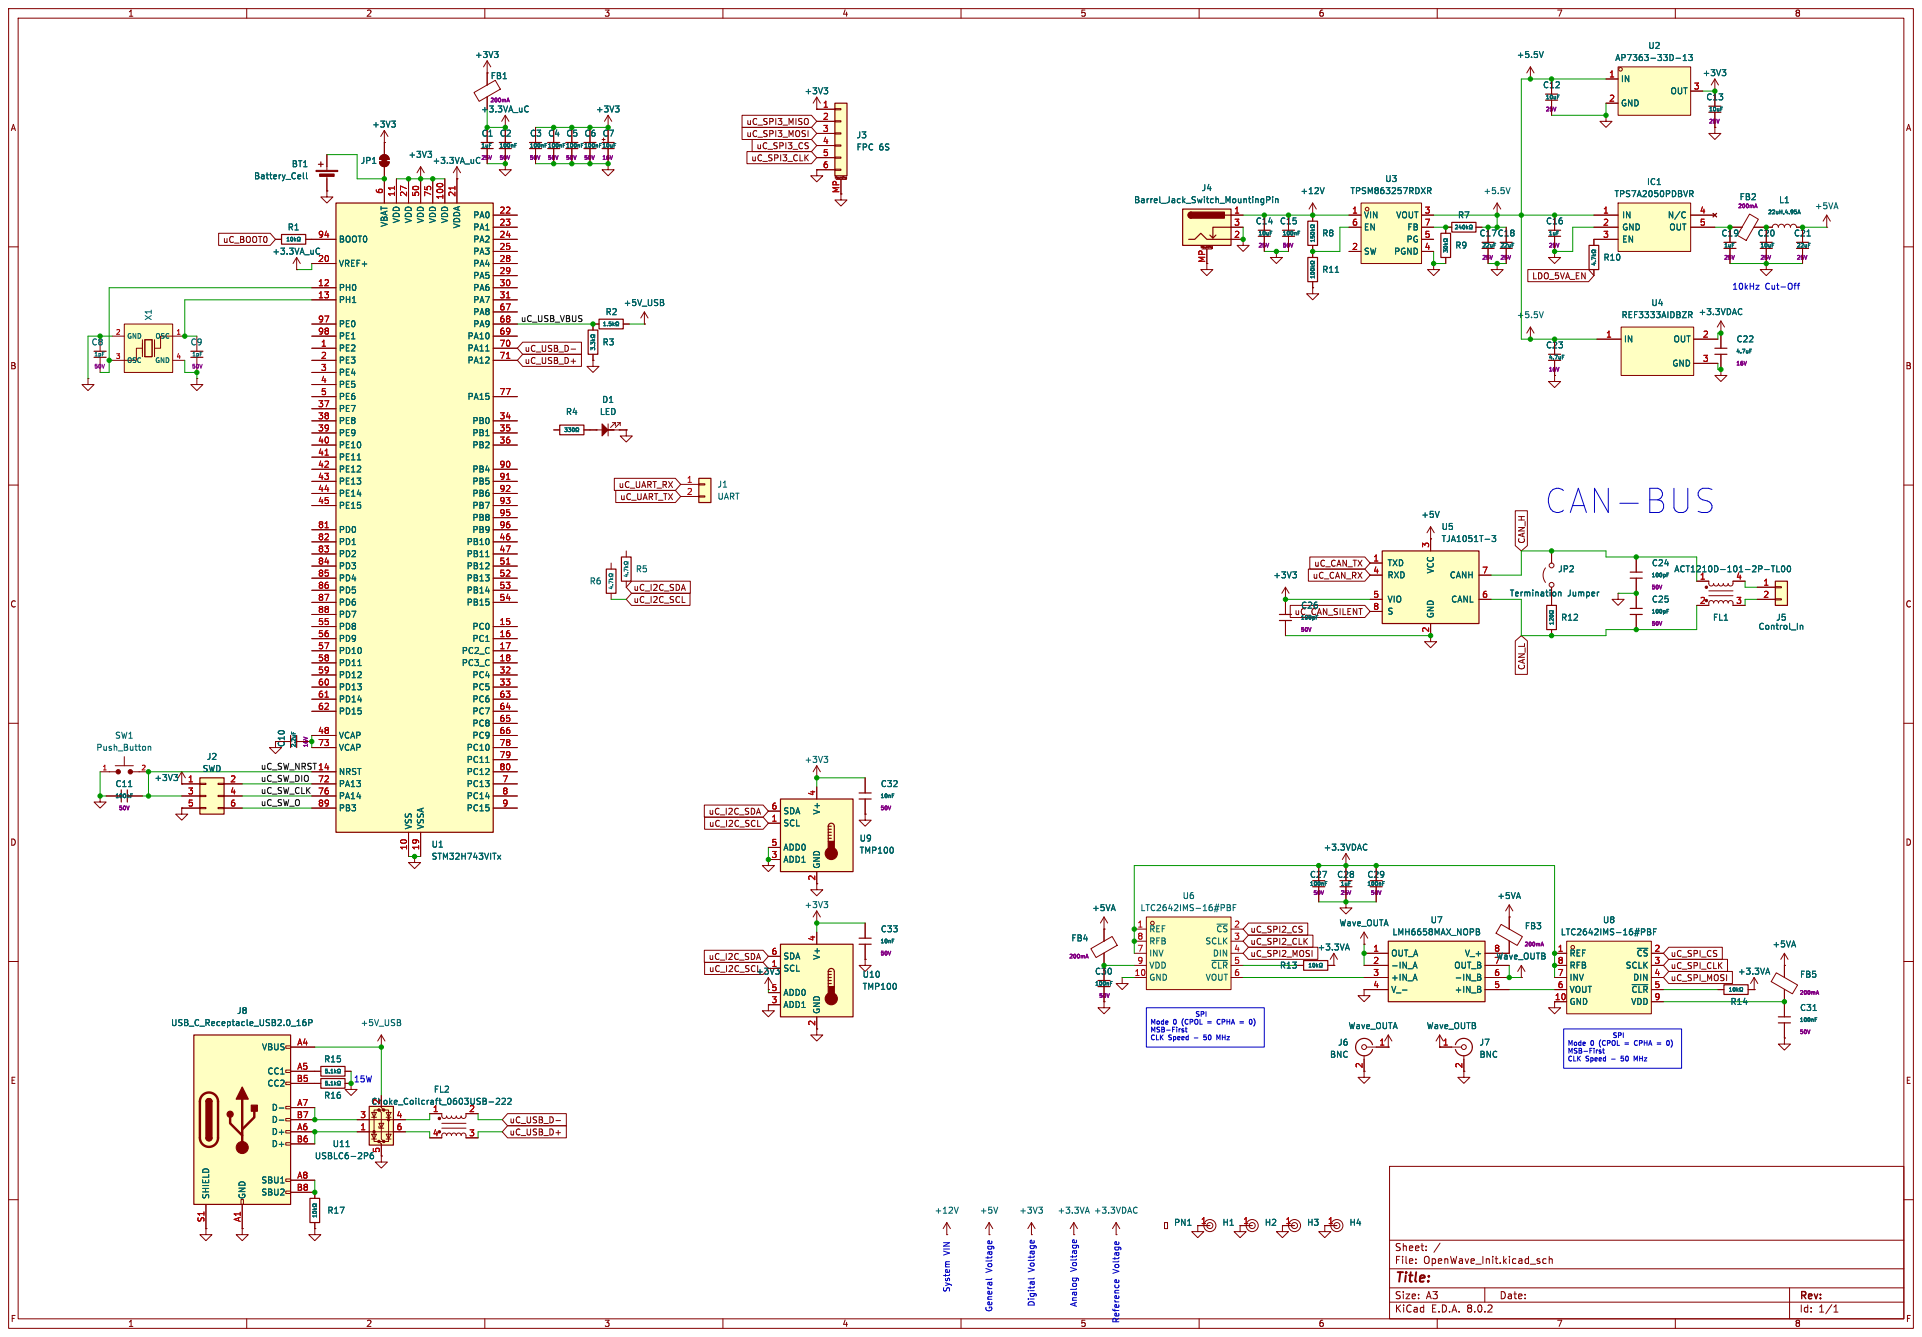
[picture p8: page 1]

10kHz Cut-Off CAN-BUS Reference Voltage

3 RXD 4 VIO 5 CANL 6 CANH 7 S

SPI Mode 0 (CPOL = CPHA = 0) MSB-First CLK Speed - 50 MHz

Id: 1/1 Title: File: OpenWave_Init.kicad_sch Sheet: /

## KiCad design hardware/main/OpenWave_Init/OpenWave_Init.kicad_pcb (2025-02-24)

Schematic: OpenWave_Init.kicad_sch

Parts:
BT1: Battery_Cell; Battery_Panasonic_CR1220-VCN_Vertical_CircularHoles
C1, C16, C19, C28: 1uF; C_0402; Voltage Rated 25V; Tolerance ±10%; Part CL05A105KA5NQNC; LCSC C52923
C2, C3, C4, C5, C6, C11, C15, C27, C29, C30, C31, C37, C38, C48, C55, C56, C57, C58, C59: 100nF; C_0402; Voltage Rated 50V; Tolerance ±10%; Part CL05B104KB54PNC; LCSC C307331
C7, C34: 10uF; C_CASE-A-3216-18(mm); Tolerance ±10%; Rated Voltage 16V; Part TAJA106K016RNJ; LCSC C7171
C8, C9: 10pF; C_0402; Voltage Rated 50V; Tolerance ±5%; Part CL05C100JB5NNNC; LCSC C32949
C10, C36: 2.2uF; C_0603; Voltage Rated 16V; Tolerance ±10%; Part CL10A225KO8NNNC; LCSC C23630
C12, C13, C14, C20, C35, C39, C54, C62: 10uF; C_0603; Voltage Rated 25V; Tolerance ±20%; Part CL10A106MA8NRNC; LCSC C96446
C17, C18, C21: 22uF; C_0805; Voltage Rated 25V; Tolerance ±20%; Part CL21A226MAQNNNE; LCSC C45783
C22, C23, C64: 4.7uF; C_0603; Voltage Rated 16V; Tolerance ±10%; Part CL10A475KO8NNNC; LCSC C19666
C24, C25, C26, C42, C46: 100pF; C_0402; Voltage Rated 50V; Tolerance ±5%; Part 0402CG101J500NT; LCSC C1546
C32, C33, C51, C63: 10nF; C_0402; Voltage Rated 50V; Tolerance ±10%; Part CL05B103KB5NNNC; LCSC C15195
C40, C47: 220nF; C_0402; Voltage Rated 16V; Tolerance ±10%; Part CL05B224KO5NNNC; LCSC C16772
C41, C45: 1.5nF; C_0603; Voltage Rated 50V; Tolerance ±10%; Part 0603B152K500NT; LCSC C1595
C43, C44: 680pF; C_0402; Voltage Rated 50V; Tolerance ±5%; Part 0402CG101J500NT
C49, C50: 6.8pF; C_0402; Voltage Rated 50V; Part 0402CG6R8C500NT; LCSC C1576
C52, C53: 15pF; C_0402; Voltage Rated 50V; Tolerance ±5%; Part 0402CG150J500NT; LCSC C1548
D1: LED; LED_0603_1608Metric
D2: SMAJ10CA; D_SMA; Part SMAJ10CA; LCSC C19077530
D3, D4, D5, D6, D7: TPRCLAMP2451ZA; D_DFN0603-2; Part TPRCLAMP2451ZA; LCSC C2936988
FB1, FB2, FB3, FB4, FB5, FB7: FB_0603; Current Rating 200mA; Tolerance ±25%; Part GZ1608D601TF; LCSC C1002
FB6: FB_0805; Current Rating 800mA; Tolerance ±25%; Part GZ2012D101TF; LCSC C1015
FL1: ACT1210D-101-2P-TL00; ACT1210D1012PTL00
FL2: Choke_Coilcraft_0603USB-222; L_CommonModeChoke_Coilcraft_0603USB
H1, H2, H3, H4: Hole, 3mm
IC1: TPS7A2050PDBVR; SOT95P280X145-5N; Mouser Part Number 595-TPS7A2050PDBVR
J1: UART; PinHeader_1x02_P2.54mm_Vertical
J2: SWD; PinHeader_2x03_P1.00mm_Vertical
J3: FPC 6S; Hirose_FH12-6S-0.5SH_1x06-1MP_P0.50mm_Horizontal
J4: Barrel_Jack_Switch_MountingPin; PRT10811
J5: Control_In; JST_XH_S2B-XH-A-1_1x02_P2.50mm_Horizontal
J6, J7: BNC; 5415025-2
J8: USB_C_Receptacle_USB2.0_16P; USB_C_Receptacle_GCT_USB4105-xx-A_16P_TopMnt_Horizontal
J9: RB1-125BAG1A; RB1125BAG1A; Mouser Part Number 950-RB1-125BAG1A
JP1: SolderJumper; SolderJumper-2_P1.3mm_Bridged2Bar_Pad1.0x1.5mm
JP2: Termination Jumper; SolderJumper-2_P1.3mm_Open_Pad1.0x1.5mm
L1: 22uH, 340mA; L_1210_3225Metric; Part SRN2012T-220K; LCSC DNP
PN1: Part_Num_JLCPCB
R1, R13, R14, R17: 10kΩ; R_0402; Overload Voltage (Max) 50V; Tolerance ±1%; Part 0402WGF1002TCE; LCSC C25744
R2: 1.5kΩ; R_0402; Overload Voltage (Max) 50V; Tolerance ±1%; Part 0402WGF1501TCE; LCSC C25867
R3: 3.3kΩ; R_0402; Overload Voltage (Max) 50V; Tolerance ±1%; Part 0402WGF3301TCE; LCSC C25890
R4, R42: 330Ω; R_0402; Overload Voltage (Max) 50V; Tolerance ±1%; Part 0402WGF3300TCE; LCSC C25104
R5, R6, R10: 4.7kΩ; R_0402; Overload Voltage (Max) 50V; Tolerance ±1%; Part 0402WGF4701TCE; LCSC C25900
R7: 240kΩ; R_0603; Overload Voltage (Max) 75V; Tolerance ±1%; Part 0603WAF2403T5E; LCSC C4197
R8: 150kΩ; R_0402; Overload Voltage (Max) 50V; Tolerance ±1%; Part 0402WGF1503TCE; LCSC C25755
R9: 30kΩ; R_0603; Overload Voltage (Max) 75V; Tolerance ±1%; Part 0603WAF3002T5E; LCSC C22984
R11: 100kΩ; R_0402; Overload Voltage (Max) 50V; Tolerance ±1%; Part 0402WGF1003TCE; LCSC C25741
R12, R26, R29: 120Ω; R_0402; Overload Voltage (Max) 50V; Tolerance ±1%; Part 0402WGF1200TCE; LCSC C25079
R15, R16: 5.1kΩ; R_0402; Overload Voltage (Max) 50V; Tolerance ±1%; Part 0402WGF5101TCE; LCSC C25905
R18: 100Ω; R_0603; Overload Voltage (Max) 75V; Tolerance ±1%; Part 0603WAF1000T5E; LCSC C22775
R19, R20: 33Ω; R_0402; Overload Voltage (Max) 50V; Tolerance ±1%; Part 0402WGF330JTCE; LCSC C25105
R21, R22, R23, R24, R33, R34, R38, R39: 49.9Ω; R_0402; Overload Voltage (Max) 50V; Tolerance ±1%; Part 0402WGF499JTCE; LCSC C25120
R25, R32: 1Ω; R_0402; Overload Voltage (Max) 50V; Tolerance ±1%; Part 0402WGF100KTCE; LCSC C25086
R27, R30: 1.2kΩ; R_0402; Overload Voltage (Max) 50V; Tolerance ±1%; Part 0402WGF1201TCE; LCSC C25862
R28, R31: 360Ω; R_0603; Overload Voltage (Max) 75V; Tolerance ±1%; Part 0603WAF3600T5E; LCSC C25194
R35: 10Ω; R_0402; Overload Voltage (Max) 50V; Tolerance ±1%; Part 0402WGF100JTCE; LCSC C25077
R36, R37: 220Ω; R_0402; Overload Voltage (Max) 50V; Tolerance ±1%; Part 0402WGF2200TCE; LCSC C25091
R40: 1MΩ; R_0402; Overload Voltage (Max) 50V; Tolerance ±1%; Part 0402WGF1004TCE; LCSC C26083
R41: 12kΩ; R_0402; Overload Voltage (Max) 50V; Tolerance ±1%; Part 0402WGF1202TCE; LCSC C25752
R43: 75Ω; R_0402; Overload Voltage (Max) 50V; Tolerance ±1%; Part 0402WGF750JTCE; LCSC C25133
U1: STM32H743VITx; LQFP-100_14x14mm_P0.5mm
U2: AP7363-33D-13; DPAK-3_L6.6-W6.1-P2.28-LS9.9-BR; LCSC Part C108723
U3: TPSM863257RDXR; QFN-7_L4.0-W3.3_TPSM863257RDXR; LCSC Part C19190416
U4: REF3333AIDBZR; SOT-23-3_L2.9-W1.6-P1.90-LS2.8-BR; LCSC Part C130016
U5: TJA1051T-3; SOIC-8_3.9x4.9mm_P1.27mm
U6, U8: LTC2642IMS-16#PBF; MSOP-10_L3.0-W3.0-P0.50-LS4.9-BL; LCSC Part C580595
U7: LMH6658MAX_NOPB; SOIC127P600X175-8N; Mouser Part Number 926-LMH6658MAX/NOPB
U9, U10: TMP100; SOT-23-6
U11: USBLC6-2P6; SOT-666
U12: W25Q128; SOIC-8_L5.3-W5.3-P1.27-LS8.0-BL; Part W25Q128JVSIQ; LCSC C97521
U13: SN74LVC8T245; VQFN-24_L5.6-W3.6-P0.50-BL-EP
U14: W5500; LQFP-48_7x7mm_P0.5mm
X1, X2: X322525MOB4SI; OSC-SMD_4P-L3.2-W2.5-BL; Frequency Tolerance ±10ppm; Part X322525MOB4SI; LCSC C9006

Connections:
+3.3VA_uC: C1.1, C2.1, FB1.2, U1.20 (VREF+), U1.21 (VDDA)
+3.3VDAC: C22.1, C27.2, C28.2, C29.2, R13.1, R14.1, U4.2 (OUT), U6.1 (REF), U6.7 (INV), U6.8 (RFB), U8.1 (REF), U8.7 (INV), U8.8 (RFB)
+3V3: C3.1, C4.1, C5.1, C6.1, C7.1, C13.1, C26.1, C32.1, C33.1, C37.1, C39.1, C54.1, C55.1, D7.2, FB1.1, FB7.1, J2.1, J3.1, J9.L1 (A_YELLOW), J9.L3 (A_GREEN), JP1.1 (A), R33.1, R34.1, R35.1, U1.11 (VDD), U1.27 (VDD), U1.50 (VDD), U1.75 (VDD), U1.100 (VDD), U2.3 (OUT), U5.5 (VIO), U9.4 (V+), U10.4 (V+), U10.5 (ADD0), U12.8 (VCC), U13.1 (V_{CCA}), U14.28 (VDD)
+5.5V: C12.1, C17.1, C18.1, C23.1, R7.2, R18.1, U2.1 (IN), U3.3 (VOUT), U4.1 (IN), U5.3 (VCC)
+5VA: C21.1, FB3.1, FB4.1, FB5.1, L1.2, U13.23 (V_{CCB}), U13.24 (V_{CCB})
+5V_USB: J8.A4 (VBUS), J8.A9 (VBUS), J8.B4 (VBUS), J8.B9 (VBUS), R2.2, U11.5 (VBUS)
+12V: C14.1, C15.1, C35.1, FB6.2, R8.1, U3.1 (VIN)
/ACT_LED: R37.1, U14.27 (ACTLED)
/LINK_LED: R36.1, U14.25 (LINKLED)
/uC_SW_CLK: R22.2, U1.76 (PA14)
/uC_SW_DIO: R23.2, U1.72 (PA13)
/uC_SW_NRST: R24.2, U1.14 (NRST)
/uC_SW_O: R21.2, U1.89 (PB3)
/uC_USB_VBUS: R2.1, R3.1, U1.68 (PA9)
/uc_QSPI_CLK: U1.36 (PB2), U12.6 (CLK)
/uc_QSPI_CS: U1.46 (PB10), U12.1 (CS#)
/uc_QSPI_IO0: U1.58 (PD11), U12.5 (DI)
/uc_QSPI_IO1: U1.59 (PD12), U12.2 (DO)
/uc_QSPI_IO2: U1.1 (PE2), U12.3 (IO2)
/uc_QSPI_IO3: U1.60 (PD13), U12.7 (IO3)
CAN_H: C24.1, FL1.1, JP2.2 (B), U5.7 (CANH)
CAN_L: C25.2, FL1.2, R12.2, U5.6 (CANL)
DAC_SPI2_CLK: U6.3 (SCLK), U13.15 (B7)
DAC_SPI2_CS: U6.2 (~CS), U13.16 (B6)
DAC_SPI2_MOSI: U6.4 (DIN), U13.14 (B8)
DAC_SPI_CLK: U8.3 (SCLK), U13.20 (B2)
DAC_SPI_CS: U8.2 (~CS), U13.21 (B1)
DAC_SPI_MOSI: U8.4 (DIN), U13.19 (B3)
GND: BT1.2 (-), C1.2, C2.2, C3.2, C4.2, C5.2, C6.2, C7.2, C8.1, C9.2, C10.1, C11.1, C12.2, C13.2, C14.2, C15.2, C16.2, C17.2, C18.2, C19.2, C20.2, C21.2, C22.2, C23.2, C24.2, C25.1, C26.2, C27.1, C28.1, C29.1, C30.2, C31.2, C32.2, C33.2, C34.2, C35.2, C36.1, C37.2, C38.2, C39.2, C40.2, C41.2, C42.2, C45.2, C46.2, C47.2, C48.2, C51.2, C52.1, C53.2, C54.2, C55.2, C56.2, C57.2, C58.2, C59.2, C62.2, C63.2, C64.2, D1.1, D2.2, D3.1, D4.1, D5.1, D6.1, D7.1, H1.1, H2.1, H3.1, H4.1, IC1.2 (GND), J2.5, J3.6, J3.MP (MountPin), J4.2, J4.MP (MountPin), J6.2 (Ext), J7.2 (Ext), J8.A1 (GND), J8.A12 (GND), J8.B1 (GND), J8.B12 (GND), J8.S1 (SHIELD), J9.1 (SHIELD_1), J9.2 (SHIELD_2), R3.2, R9.2, R11.2, R15.1, R16.1, R17.2, R43.2, U1.10 (VSS), U1.19 (VSSA), U1.26 (VSS), U1.49 (VSS), U1.74 (VSS), U1.99 (VSS), U2.2 (GND), U3.4 (PGND), U4.3 (GND), U5.2 (GND), U6.10 (GND), U7.4 (V_-), U8.10 (GND), U9.2 (GND), U9.3 (ADD1), U9.5 (ADD0), U10.2 (GND), U10.3 (ADD1), U11.2 (GND), U12.4 (GND), U13.11 (GND), U13.12 (GND), U13.13 (GND), U14.3 (AGND), U14.9 (AGND), U14.14 (AGND), U14.16 (AGND), U14.19 (AGND), U14.29 (GND), U14.48 (AGND), X1.2 (GND), X1.4 (GND), X2.2 (GND), X2.4 (GND)
LLT_DIR: U13.2 (DIR)
LLT_OE: U13.22 (~OE)
unnamed: BT1.1 (+), C38.1, JP1.2 (B), U1.6 (VBAT)
unnamed: C10.2, U1.73 (VCAP)
unnamed: C20.1, FB2.2, L1.1
unnamed: C36.2, U1.48 (VCAP)
unnamed: C41.1, R26.2, R27.1
unnamed: C43.1, R27.2, R28.1
unnamed: C44.1, R30.2, R31.1
unnamed: C45.1, R29.2, R30.1
unnamed: C51.1, R38.2, R39.2
unnamed: C56.1, C57.1, C58.1, C59.1, C62.1, FB7.2, U14.4 (AVDD), U14.8 (AVDD), U14.11 (AVDD), U14.15 (AVDD), U14.17 (AVDD), U14.21 (AVDD)
unnamed: D1.2, R4.2
unnamed: D2.1, FB6.1, J4.1
unnamed: FL2.1, U11.4 (I/O2)
unnamed: FL2.4, U11.6 (I/O1)
unnamed: IC1.3 (EN), R10.1
unnamed: C16.1, C34.1, IC1.1 (IN), R10.2, R18.2
unnamed: C19.1, FB2.1, IC1.5 (OUT)
unnamed: D5.2, J2.2, R23.1
unnamed: C11.2, D6.2, J2.3, R24.1
unnamed: D4.2, J2.4, R22.1
unnamed: D3.2, J2.6, R21.1
unnamed: FL1.3, J5.1
unnamed: FL1.4, J5.2
unnamed: C40.1, J6.1 (In), R25.2
unnamed: C47.1, J7.1 (In), R32.2
unnamed: J8.A5 (CC1), R15.2
unnamed: J8.B5 (CC2), R16.2
unnamed: J8.A6 (D+), J8.B6 (D+), U11.3 (I/O2)
unnamed: J8.A7 (D-), J8.B7 (D-), U11.1 (I/O1)
unnamed: J8.A8 (SBU1), J8.B8 (SBU2), R17.1
unnamed: C48.1, J9.R3 (CT), R35.2
unnamed: J9.L4 (K_GREEN), R37.2
unnamed: J9.L2 (K_YELLOW), R36.2
unnamed: C49.2, J9.R7 (RD+)
unnamed: C50.2, J9.R8 (RD-)
unnamed: J9.R1 (TD+), R33.2, U14.2 (TXP)
unnamed: J9.R2 (TD-), R34.2, U14.1 (TXN)
unnamed: JP2.1 (A), R12.1
unnamed: R41.2, R42.1
unnamed: R42.2, R43.1
unnamed: R1.2, U1.94 (BOOT0)
unnamed: R20.2, U1.29 (PA5)
unnamed: R19.2, U1.42 (PE12)
unnamed: C8.2, U1.12 (PH0), X1.3 (OSC)
unnamed: C9.1, U1.13 (PH1), X1.1 (OSC)
unnamed: R8.2, R11.1, U3.6 (EN)
unnamed: R7.1, R9.1, U3.7 (FB)
unnamed: C30.1, FB4.2, U6.9 (VDD)
unnamed: R26.1, U6.6 (VOUT)
unnamed: R13.2, U6.5 (~CLR)
unnamed: C42.1, R28.2, U7.3 (+IN_A)
unnamed: C46.1, R31.2, U7.5 (+IN_B)
unnamed: FB3.2, U7.8 (V_+)
unnamed: C31.1, FB5.2, U8.9 (VDD)
unnamed: R29.1, U8.6 (VOUT)
unnamed: R14.2, U8.5 (~CLR)
unnamed: C63.1, U14.22 (1V2O)
unnamed: R41.1, U14.10 (EXRES1)
unnamed: C50.1, R39.1, U14.5 (RXN)
unnamed: C49.1, R38.1, U14.6 (RXP)
unnamed: C64.1, U14.20 (TOCAP)
unnamed: C52.2, R40.1, U14.30 (XI/CLKIN), X2.3 (OSC)
unnamed: C53.1, R40.2, U14.31 (XO), X2.1 (OSC)
W55_INT: U14.36 (~INT)
W55_RST: U14.37 (~RST)
W55_SPI2_CS: U1.96 (PB9), U14.32 (~SCS)
W55_SPI2_MISO: U1.16 (PC1), U14.34 (MISO)
W55_SPI2_MOSI: U1.17 (PC2_C), U14.35 (MOSI)
W55_SPI2_SCK: U1.84 (PD3), U14.33 (SCLK)
Wave_OUTA: C43.2, R25.1, U7.1 (OUT_A), U7.2 (-IN_A)
Wave_OUTB: C44.2, R32.1, U7.6 (-IN_B), U7.7 (OUT_B)
uC_BOOT0: R1.1
uC_CAN_RX: U1.81 (PD0), U5.4 (RXD)
uC_CAN_SILENT: U5.8 (S)
uC_CAN_TX: U1.82 (PD1), U5.1 (TXD)
uC_I2C_SCL: R6.2, U9.1 (SCL), U10.1 (SCL)
uC_I2C_SDA: R5.2, U9.6 (SDA), U10.6 (SDA)
uC_SPI2_CLK: R20.1, U13.9 (A7)
uC_SPI2_CS: U1.28 (PA4), U13.8 (A6)
uC_SPI2_MOSI: U1.31 (PA7), U13.10 (A8)
uC_SPI3_CLK: J3.3, U1.78 (PC10)
uC_SPI3_CS: J3.2, U1.77 (PA15)
uC_SPI3_MISO: J3.4, U1.79 (PC11)
uC_SPI3_MOSI: J3.5, U1.80 (PC12)
uC_SPI_CLK: R19.1, U13.4 (A2)
uC_SPI_CS: U1.41 (PE11), U13.3 (A1)
uC_SPI_MOSI: U1.44 (PE14), U13.5 (A3)
uC_UART_RX: J1.1
uC_UART_TX: J1.2
uC_USB_D+: FL2.2, U1.71 (PA12)
uC_USB_D-: FL2.3, U1.70 (PA11)

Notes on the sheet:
SPI Mode 0 (CPOL = CPHA = 0) MSB-First CLK Speed - 50 MHz
CAN-BUS
11 pF Crystal 5-7 pF stray from STM
15W
Digital Voltage
POWER
Temp.
Close to Connector
fc = 906 , 916 kHz ζ = 0.49 f = 795 kHz
General Voltage
11 pf Crystal 7.5 pf caps 3-4 pf stray
1001010
Memory
Logic Level 5-3.3
Analog Voltage
fc = 725-800kHz
check 100ohm diff imp
1001000
System VIN
UI Board Conn
USB
Do not ask. =12.4k
10kHz Cut-Off
DAC, OPAMP
Reference Voltage

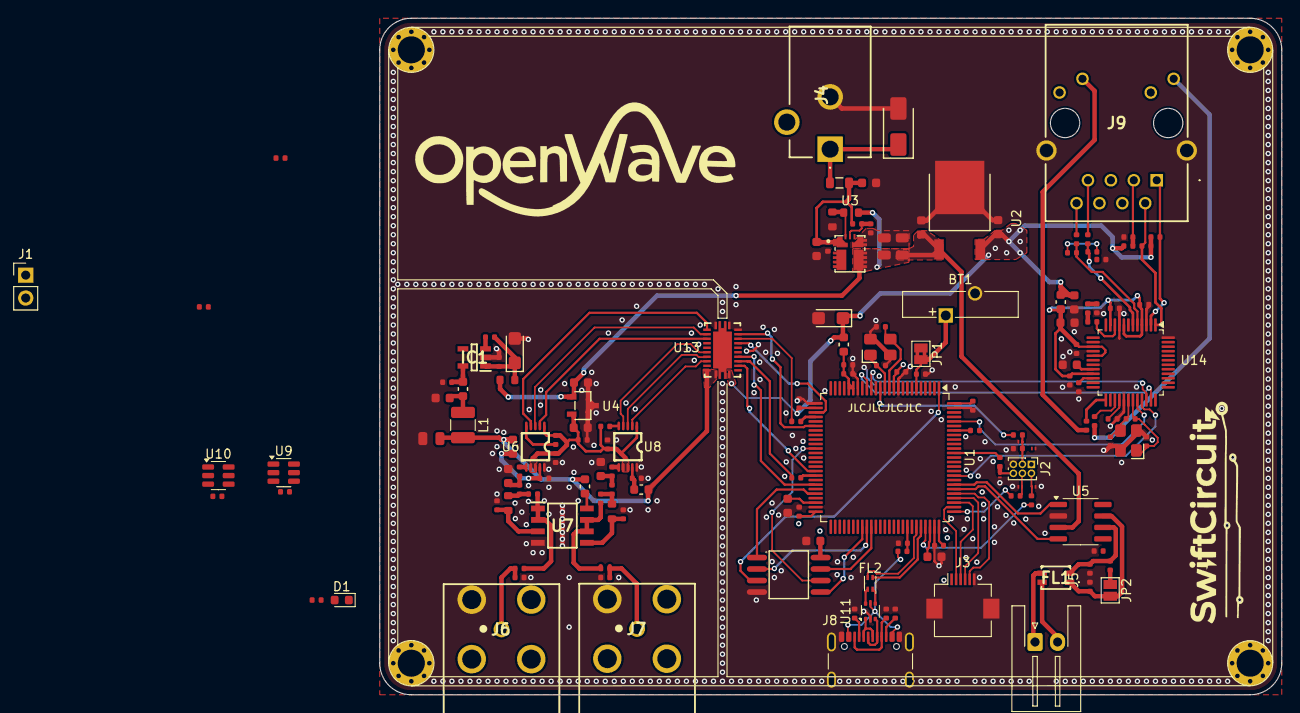
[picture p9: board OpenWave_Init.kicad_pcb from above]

Board: 4 copper layers, 100.0 x 75.0 mm, 156 parts (0 on the bottom side), 114 nets.

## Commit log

2025-02-19 Schematic, Design Changes
    [OpenWave_Init.kicad_sch]
2025-02-24 WA5500 implementation
    [OpenWave_Init.kicad_pcb, OpenWave_Init.kicad_sch]
2025-02-24 fixed ethernet, impedance, new swiftcircuit logo, arranged schematic
    [OpenWave_Init.kicad_pcb, OpenWave_Init.kicad_sch]

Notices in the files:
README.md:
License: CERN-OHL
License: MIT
